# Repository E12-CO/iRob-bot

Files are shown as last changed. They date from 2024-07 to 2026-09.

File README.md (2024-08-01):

# iRob-bot

iRob-bot is a robot testing platform for Arduino and ROS2.
The goal is to have a autonomous robot with good odometry accuracy while having a simple motion control system that capable of manuvering complex movement.  

This robot is a part of R&D project at Robot club engineering KMITL (RB26).

# Why iRob-bot ?

Our club has a long experience with Mechanical and Electronics design. We have been doing these kind of works for almost three decades. But when it comes to autonomous robot. We're very new to this and still lacking a lot of fundamental skill such as motion control and planning. At the competition, our manual control robot worked very hard to gain a good amount of score, while our autonomous robot struggled to do a mission, let alone walking straight. 

Back in december 2023, there was a competition called ```CRU Robot Games```. 
This competition which each team has to compete using one manual control robot 
and one autonomous robot. In fact, we also participated in this same competition 
but without much success as we are very new to autonomous robot. (I personally participated back in 2022, That also my first time working with closed-loop 
control of DC motor with the autonomous robot, but again without much success).

There was a 3 wheeled omni robot from a team ```iRap```(robotics club from KMUTNB). I was intrigued by their autonomous robot, especially the motion control. Somehow it can do advanced motion like translational motion while also rotates 
around its own axis, or following the curve arc while also rotates around.

At the time I saw their robot in-action. I've had some previous experience from joining the club and working with holonomic robot (using mecanum/swiss wheel) . 
But nothing of us every came close to theirs. And we are still using ```robot oriented``` control. At best our robot did equiped with encoder and PI speed controlled for motor. But the robot still lack of a good motion
control system.

Tragidy strikes. Our club got critizied with a surprise budget cut by half. The reason was that we ```don't have a real work``` a.k.a we never win any of these competition despite a lots of work behind and knowledge that we gained and poured into each competition.

In out defense, we decided to start a R&D project to research and test out around the topic of robotics. The goal is to gain knowledge as much as possible to be used in competition. But also to prove them that every cent that we spend is turned into know-how that we then pass down to the next club member generation. 

This year is my last year at university as I will (hopefully) be graduated soon. I want to do something to help our junior members as a payback to what this club had taught me from the past 2 years. So I set out to learn and implement the motion control system. 

This is a good oppurtunity for me to revisit what I've seen back in 2023. I finally came up with a robot test platform called ```iRob-bot```, basically I "rob" the idea of using 3 wheeled omni robot from iRap, hence the name iRob-bot. along with the motion controller called ```Maneuv3r``` that will be on arduino and ROS2. 

# General Information

- Dimension : ⌀ : 145.4mm, Height included LiDAR : ~ 130mm
- Weight : ~0.4 kg
- Drivetrain ```omnidirectional 3 wheels (omni-wheel)```
- Motor ```N20 motor with 1:48 gearbox and 7PPR AB quadrature encoder```
- Drive ```DRV8835 on custom breakout board(sees Electronics folder)```
- Main controller ```ESP32 WROOM32```
- Odometry sensors
    - ```Wheel encoder``` (Moving average filtering)    
    - ```ADNS-5050``` optical flow sensor 
	- Wheel odometry and Optical Flow odometry fusion using ```complementary filter```
- IMU via I2C (9 axis GY-85 module)
    - ```ADXL345``` 3 axis Accelerometer (currently unused until I can implement EKF)
    - ```ITG3205``` 3 axis Gyro sensor
    - ```HMC5883L``` 3 axis Mag sensor (currently unused until I can implement EKF)
- LiDAR
    - ```HLS-LF2CD``` LiDAR (currently unused until I implemented ROS2 node)
- Digital Control running at ```125Hz```
    - PI speed control (No torque control)
    - PID position and orientation control
- ESP32 Dual core
    - Core 0 is working on Low-level control system
    - Core 1 is responsible for Networking task (BR/EDR or WiFi) and LiDAR reading (Work in progress)

# Folders
- Documents : Schematic and diagram PDFs and more soon.
- Electronics : Electronics design file (EAGLE cad and Fusion 360 format)
- Firmware : Arduino firmware
- Hardware : CAD design of the robot in Fusion 360 archive
- Software : ROS2 node (Coming soon)

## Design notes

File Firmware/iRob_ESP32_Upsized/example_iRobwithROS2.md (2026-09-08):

# Driving iRob with `teleop_twist_keyboard`

This guide is for anyone using the iRob ROS 2 workspace with the four-wheel
omni ESP32 robot. It assumes you are already in a terminal where ROS 2 is
available and the `ROS_iROB_V0` workspace overlay has been sourced.

The control path is:

```text
teleop_twist_keyboard -- /cmd_vel --> iRob_controller
    -- /irob_motor_cmd --> iRob_interface -- /dev/ESP32 --> ESP32
```

The current controller configuration uses the `Omni4` kinematic plugin. You
do not need to publish motor commands yourself; the controller converts the
keyboard velocity commands into four motor commands.

## Before driving

1. Turn off or lift the robot so the wheels cannot move unexpectedly.
2. Upload the ESP32 sketch in this directory. The firmware serial rate is
   `115200` baud.
3. Connect the ESP32 by USB. Ensure `/dev/ESP32` exists and points to the
   connected ESP32:

   ```bash
   ls -l /dev/ESP32
   ```

   If it does not exist, install the udev rule once:

   ```bash
   sudo cp src/iRob_bot_ros2/irob_controller/esp32.rules /etc/udev/rules.d/
   sudo udevadm control --reload-rules
   ```

   Unplug and reconnect the ESP32 after installing the rule.
4. Build the workspace after any source-code or parameter-file change, then
   source its overlay:

   ```bash
   colcon build --packages-select irob_interface irob_controller irob_launcher --symlink-install
   source install/setup.bash
   ```

## Start the robot nodes

Open three terminals after completing the setup above. ROS commands in each
terminal must use the same ROS domain and workspace overlay.

### Terminal 1: ESP32 interface

This node sends motor commands to the ESP32 and publishes motor feedback.

```bash
ros2 launch irob_launcher irob_interface_esp32.launch.py
```

### Terminal 2: kinematic controller

This node receives `/cmd_vel` and calculates the four wheel speeds.

```bash
ros2 launch irob_launcher irob_controller.launch.py
```

### Terminal 3: keyboard teleoperation

Install the keyboard package if needed:

```bash
sudo apt install ros-$ROS_DISTRO-teleop-twist-keyboard
```

Start at a low speed:

```bash
ros2 run teleop_twist_keyboard teleop_twist_keyboard --ros-args -p speed:=0.15 -p turn:=0.5
```

Keep this terminal focused while driving. `teleop_twist_keyboard` publishes
`geometry_msgs/msg/Twist` on `/cmd_vel`; no remapping is required.

## Keyboard controls

```text
u  i  o
j  k  l
m  ,  .
```

- `i`: forward
- `,`: backward
- `j` / `l`: strafe left / right
- `u`, `o`, `m`, `.`: diagonal motion
- `q` / `e`: rotate counter-clockwise / clockwise
- `k` or `Space`: stop immediately

For this Omni4 firmware, motor order is left-front, left-back, right-back,
right-front. If a direction is wrong, stop the robot and correct motor wiring
or the wheel-direction configuration before further driving.

## Verify the command path

Run these in a fourth sourced terminal while pressing a teleop key:

```bash
ros2 topic info /cmd_vel
ros2 topic echo /irob_motor_cmd
```

`/cmd_vel` should have `teleop_twist_keyboard` as a publisher and
`iRob_controller` as a subscriber. `/irob_motor_cmd` should change while a
movement key is pressed.

## Common problems

| Problem | Check |
| --- | --- |
| `/dev/ESP32` does not exist | Reconnect the board and install the udev rule in the “Before driving” section. |
| Interface cannot open the serial port | Ensure no packet-test program or serial monitor is using `/dev/ESP32`; confirm your user belongs to the `dialout` group. |
| Keyboard keys do not move the robot | Keep the teleop terminal focused, then run `ros2 topic info /cmd_vel` and confirm the controller is running. |
| Robot moves in the wrong direction | Press `Space` immediately. Verify the Omni4 motor order and wheel directions before trying again. |
| Robot does not stop after closing teleop | Use the physical emergency stop or remove motor power; do not rely on a closed terminal as a safety stop. |

## Safety

Lift the wheels off the ground for the first test. Keep a hand near the power
disconnect or emergency stop. Always press `Space` or `k` before switching
terminals or stopping a ROS node.

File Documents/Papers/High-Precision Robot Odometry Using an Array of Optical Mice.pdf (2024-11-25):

# High-Precision Robot Odometry Using an Array of Optical Mice

Steven Bell Student Member, IEEE

IEEE Student Member No. 90691022

Oklahoma Christian University

18 March 2011

ORIGINALITY STATEMENT
I was the sole author of this paper, and all of the images, diagrams and graphs were captured in the lab or created by me except where noted. The algorithms for calculating the robot position using an array of sensors are based on research by others, but the use of surface quality measurements as a means of checking displacement readings is original. I built and programmed the test system described within this paper to validate the concepts and algorithms.

ACKNOWLEDGEMENTS
I am grateful for Dr. David Waldo’s guidance during this project and for his support of the Oklahoma Christian IEEE student branch, and to Dr. Bill Ryan for his help in the manufacturing aspects of this work. I would also like to thank Avago Technologies, Marshall Electronics, and M12 Lenses, Inc, for supplying free and discounted parts for this project.

CONTENTS

I | Introduction | 3
I-A | Prior research | | 3
I-B | Conditions for mouse use | | 4
II | Sensor design | 4
II-A | Hardware design | | 5
II-B | Software driver | | 5
III | Motion tracking | 5
IV | Error reduction | 7
IV-A | Integration of multiple sensors | | 7
IV-B | Use of encoder data | | 7
IV-C | Use of surface quality | | 8
V | Additional uses | 8
VI | Conclusions and Future work | 8
References | 9
Appendix | 10
A | Optical mouse theory of operation | | 10
B | Lens comparison and selection | | 10

Abstract

This paper describes a robot position tracking system based on a set of six optical mice. Each mouse sensor uses a lens which results in higher tracking speeds and allows the sensor to be placed centimeters, rather than millimeters, from the floor. The sensors’ tracking and data reporting characteristics are discussed, and an algorithm is presented to determine a robot’s motion from the sensor readings. Techniques for error detection and correction are presented, along with methods to use the sensor for line following and edge detection.

I. INTRODUCTION
F

OR decades, dead-reckoning has been a staple of mobile robot navigation. For ground-based robots, this has typically been accomplished by using a set of shaft encoders mounted to the robot’s wheels to measure speed and distance. While this method is simple and well-tested, it suffers from one primary drawback: any time the wheel slips on the surface it will cause an error in the position measurement. This is a major handicap for omnidirectional drivetrains based on omniwheels or mecanum wheels, which by their nature slide easily and can slip in any direction [1]. The encoder approach also suffers in competition environments where the robot is likely to physically collide with obstacles or even be pushed by other robots, causing wheel slip.
Traditionally, computer mice have been plagued with many of the same problems. Achieving accurate motion with a mechanical ball is difficult due to surface differences, dust, and wear. Optical mice based on high-speed optical flow solve these problems, and they have completely supplanted traditional ball mice over the last ten years. The underlying operation of optical mouse sensors has been discussed extensively in prior research [2]–[4], and is summarized in Appendix A.
This paper presents a means of using optical mice as position sensors by pointing them at the floor and reading motion data from them. A robot navigation system based on optical mice has several notable advantages over wheel-based encoders. First, it has no moving parts and does not need to be in contact with the floor, which ultimately reduces friction and wear on the system. Second, all of the mouse chips on the market track motion in two dimensions simultaneously, and do so at increasingly high resolutions - up to five thousand counts per inch (CPI) [5]. Mouse chips typically come in 8 or 16-pin integrated circuit packages, which means they are both small and easy to mount. Finally, the sensors are abundant and inexpensive: Avago Technologies has shipped over 0.8 billion mouse sensors [6], and typical chips cost less than a dollar apiece in bulk.
A. Prior research

Researchers, undergraduates, and hobbyists have been experimenting with optical mice as sensors for robot navigation for the last decade. Most of the published papers and reports take one of three approaches: One set of projects has focused on the validation of the optical mouse sensor as a means of robot position tracking and the development of algorithms to achieve robust 3-degree-of-freedom (3-DOF) tracking with an array of sensors [7]–[12]. That is, they combine the data from multiple sensors to measure a robot’s translation in two dimensions plus rotation. Nearly all of these projects use the mouse chips in their intended configuration - they are placed within millimeters of the tracking surface and utilize the commercial-off-the-shelf (COTS) lens and illumination LED. Many of these systems use complete circuit boards and even plastic shells taken from commercial optical mice.
A second area of research has been to carefully characterize particular sensors. Several findings are particularly relevant: although the sensor measures motion very precisely and repeatably [4], it has limitations.
While the sensor is within its working height range, the resolution (in CPI) is a linear function of height. When the sensor is raised further from the surface, it sees a larger patch of the tracking surface, and each pixel represents a larger distance. Because the sensor tracks movement using pixel displacement, one inch of motion will give a higher distance count when the sensor is close than when it is far away [3]. When the sensor is outside of its working focal range, the measured distance drops off sharply.
The measured displacement appears to vary depending on the orientation of the sensor relative to the direction of motion [3], [4]. There are two reasons for this. Many common surfaces - including paper, which is a popular test surface - exhibit a grain. That is, they have a directional surface pattern that may result in better tracking in some dimensions versus others. Moreover, [4] and [13] show that one axis consistently reports higher measurements than the other - a surprising find, given that the chip’s internal algorithm is presumably indifferent to the movement direction. This is caused by the fact that the standard design for optical mice includes a single light source along one axis, causing it to track more accurately than the other [13]. Using two orthogonal light sources eliminates this effect.
Finally, the sensor readings are strongly dependent on the surface, which means that the sensor must be calibrated for each new environment, and it will not work reliably in situations where the surface is not uniform [3].
The third research area is the application of optical mice to a variety motion tracking problems where the robot is not within millimeters of the tracking surface. This requires the use of a non-standard lens to refocus the light onto the sensor at a different distance. This approach has been shown to work across a wide range of distances, from mobile robots less than 2 cm above the surface [14] to robots flying tens of meters above the ground [15]. This paper synthesizes these threads of research to create a system based on a set of optical mice which can be used for robust and precise robot navigation.
B. Conditions for mouse use

Based on the research discussed above, there are several constraints which inform the use of optical mice as planar 3-DOF position sensors. First, the tracking surface should have a uniform and unstructured texture - that is, it should not have a grain or other directional pattern which will favor tracking in one direction over another. Second, the environment must allow calibration of the sensors prior to their use. Finally, the surface should be flat, so that the distance from the sensor to the surface is essentially constant.
These constraints make the optical mouse unsuitable for many applications, but in other domains - such as small scale robotics contests - these constraints are not a problem. With these limitations in mind, we proceed with the design of our system.

II. SENSOR DESIGN

The proposed system is a small, 2-wheel differential drive robot for the IEEE Region 5 robotics competition which uses a set of six optical mouse sensors for navigation. Four sensors are located across the front and two are placed in the back corners. A rendering of the robot base is shown in Figure 1. Encoders are also mounted on the wheels for speed control; their integration is described in Section IV-B. The competition playing field is made of fiberboard painted flat white, which provides a uniform tracking surface for the mouse sensors.

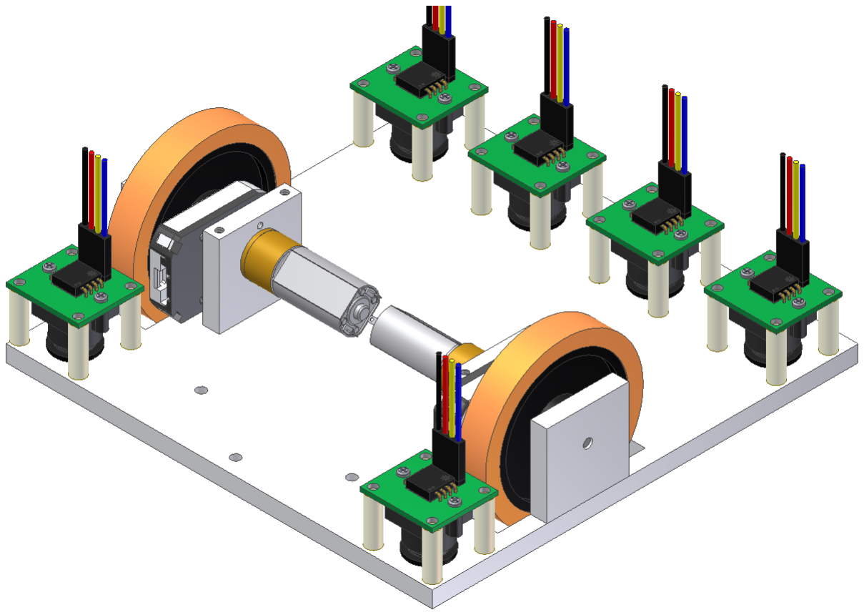
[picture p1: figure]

Figure 1: Simplified rendering of the robot base showing the location of the six sensors.

[16] and [2] show mathematically that for optimal performance, the array of sensors should be evenly spaced, located as far from the center of the robot as possible. Because of the additional sensor uses described in Section V, our placement deviates from the optimum. However, the sensors are all located near the edge of the robot, which will still provide very good tracking.

A. Hardware design
The sensor system is based on the Avago Technologies ADNS-2610 and the pin-compatible ADNS-5060. Both sensors have the same form factor and communication interface; the primary difference is in the rated tracking speed. The mouse chip is mounted on a custom printed circuit board which contains a header for connection to a microcontroller and decoupling capacitors as suggested by the sensor datasheet. A COTS lens holder is screwed onto the bottom of the PCB and a standard M12 lens is threaded into it. By using a standard lens mount, it is simple to connect a variety of lenses to the system for testing. A lens with a 3.6 mm focal length was selected for the ADNS-2610; a detailed comparison of lens focal lengths and selection criteria is given in Appendix B. An exploded view of the sensor assembly is shown in Figure 2a and a photograph of the assembled unit in Figure 2b.

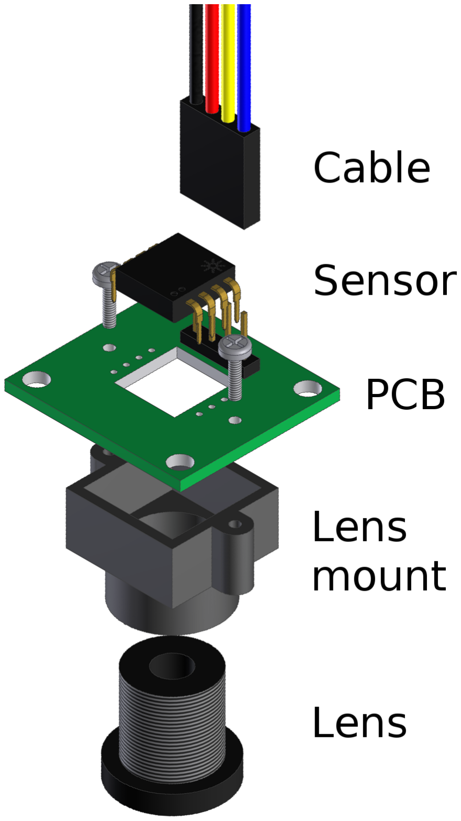
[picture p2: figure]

(a) Exploded view of the sensor assembly

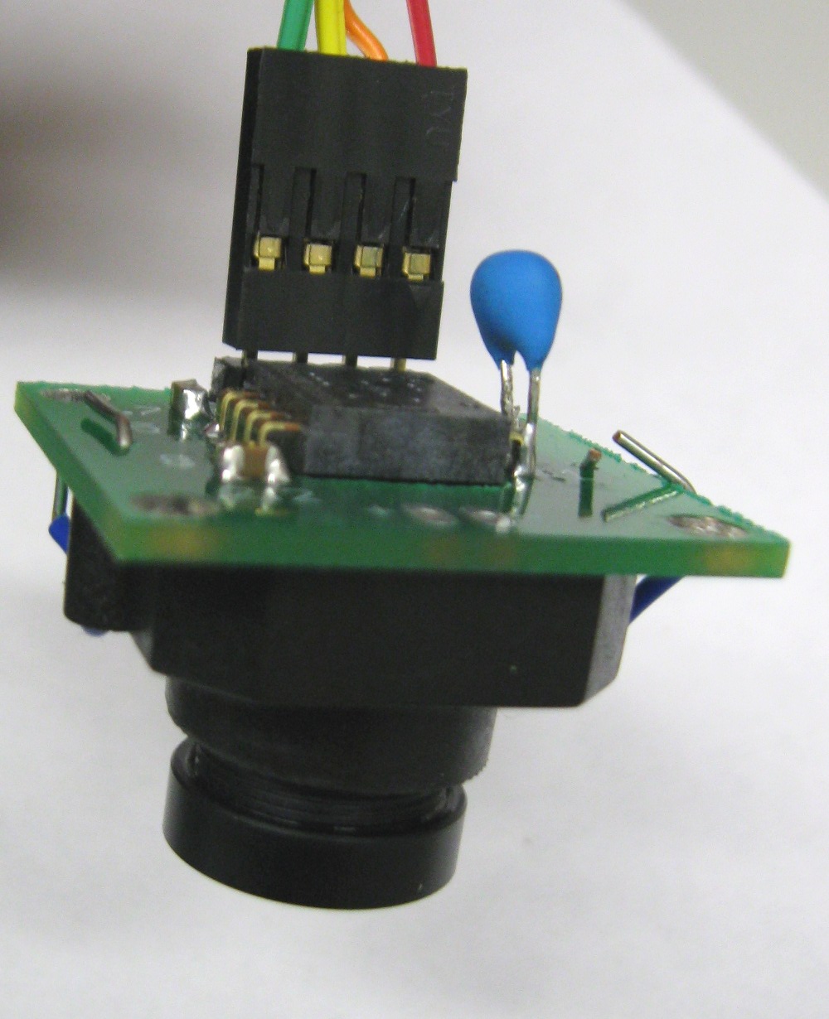
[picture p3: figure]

(b) Photograph of the sensor assembly

Figure 2: Rendering and photograph of the sensor assembly. 3-D models of mouse chip and lens mount courtesy of Avago Technologies and Marshall Electronics respectively.

B. Software driver
Most of Avago’s mouse chips share a common synchronous serial interface to a set of internal registers which contain the tracking data. In a typical mouse, a microcontroller interfaces with the mouse chip, integrates the buttons and mouse wheel, and provides a USB connection to the host PC. In our application, the control hardware (an Arduino microcontroller board) is wired directly to to the mouse sensor so that we have direct access to all of the chip’s registers, not merely the motion reports. The chip provides several pieces of data:
- X and Y differential motion values, which report the number of “counts” since the last time the register was read.
- A Surface Quality (SQUAL) measurement, which gauges how suitable the surface is for tracking. A higher SQUAL value indicates a higher number of tracking features, and generally corresponds to a more accurate distance measurement. Lower SQUAL values indicate that the surface is especially smooth and featureless or that the camera is not properly focused on the tracking surface.
- The imager shutter speed, which can be used to derive the brightness of the tracking surface. High (longer) shutter values indicate a darker surface, low values indicate a bright surface.
- The sensor also provides a means of capturing image data directly from the sensor, which was used to obtain the mouse images presented in the Appendix.
The software provides methods for reading each of these values, and communicates with a GUI running on a PC which can display the data in real time.

III. MOTION TRACKING
There are three important frames of reference in the motion tracking problem, which are shown in Figure 3. The first is the absolute coordinate frame, designated by the Cartesian coordinates XA and YA. The second is the robot frame of reference, specified by XR and YR. The final reference frame is aligned with each sensor’s measurement axes and is designated xi and yi
. Note that although only one mouse sensor is shown in Figure 3, there can be an arbitrary number of mice, and their reference frames will be labeled x1, x2, x3 and so forth. We can also reference these points using a polar coordinate system, which will be useful in later derivations. The robot’s position in absolute coordinates is given by rR and θR, while each mouse’s position is given by ri and θi
. Each mouse’s
rotation relative to the robot is labeled φi

Figure 3: Important frames of reference: absolute coordinates, robot coordinates, and mouse coordinates.

Using these definitions, we can relate the 3-dimensional motion of the robot to the motion of each mouse.

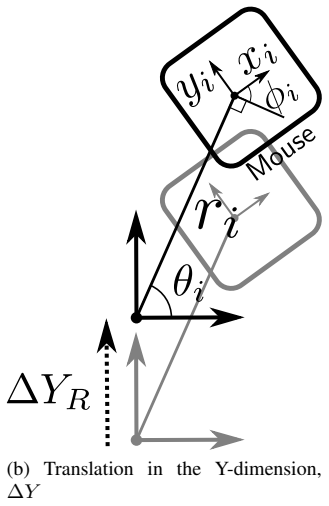
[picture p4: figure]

(a) Translation in the X-dimension, ∆X | (b) Translation in the Y-dimension,
(c) Rotation about the robot center, ∆ω

Figure 4: Three possible movements for the robot base and the resulting motion measured by the optical mouse sensor.

If the robot base translates by ∆XR as shown in Figure 4a, then the mouse will also translate by ∆XR. Because the mouse has a different orientation than the robot, the values measured by the mouse axes xi and yi will be:

xi = ∆XR · sin (θi + φi) | (1)
yi = ∆XR · cos (θi + φi) | (2)

Likewise, if the robot translates by ∆YR, the sensors will measure

xi = −∆YR · cos (θi + φi) | (3)

yi = ∆YR · sin (θi + φi) | (4)

If the robot rotates around its center by ∆ω (where ω is in radians), the mouse will travel a distance of ∆ω · ri
The measurements along the mouse axes will be

xi = −∆ω · ri

- cos (φi) | (5)

yi = ∆ω · ri

- sin (φi) | (6)

We can add equations 1, 3, and 5 to get the total motion measured by the sensor x-axis:

xi = ∆XR · sin (θi + φi) − ∆YR · cos (θi + φi) − ∆ω · ri

- cos (φi) | (7)

And we can do the same for the y-axis with equations 2, 4, and 6:

yi = ∆XR · cos (θi + φi) + ∆YR · sin (θi + φi) + ∆ω · ri

- sin (φi) | (8)

Since we know the motion of each sensor, we can put those values into equations 7 and 8 and solve for ∆X, ∆Y , and ∆ω. With only one sensor, we have 2 equations and three unknowns, but each additional sensor provides two more solutions to these equations. With six sensors, we have a total of 12 equations and three unknowns. This is an overconstrained system, and because of errors there will be no solution which can satisfy all 12 equations. Instead we use a linear least squares algorithm to find the “best fit” for the data. Mathematically, this is equivalent to finding the linear trendline for a set of data points.
The answer to the linear least squares optimization can be found by creating a matrix with the coefficients (which for a given mouse configuration are constants) and taking the Moore–Penrose pseudoinverse. Multiplying the pseudoinverse matrix by the measurement matrix produces a matrix with the estimated robot movements ∆X, ∆Y , and ∆ω [2]. Once the robot’s relative motion is determined, translating this value back to absolute coordinates is trivial.

IV. ERROR REDUCTION
Although the individual sensors are very accurate and averaging them together provides even greater accuracy, they are still subject to errors. Ideally, the system should detect which sensor readings are incorrect and discard them in favor of measurements known to be more correct. There are several techniques which we can use to detect these errors, which are described in the following sections.
After detecting the errors, we must account for them in the position estimation algorithm described in the previous section. To do this, we extend the linear-least-squares algorithm to be a weighted linear-least-squares algorithm. That is, rather than trying to make the solution fit all of the points equally, it favors some over others. Each measurement is given a weight: A high weighting factor causes the derived equation to fit a data point very closely (at the expense of a looser fit at other points), while a factor of zero forces a data point to be completely ignored.
A. Integration of multiple sensors
In [7], several assumptions are made about the characteristics of the mouse sensors which are used to detect and correct for errors. In general, mouse sensors do not measure a distance greater than the actual distance traveled. The optical flow algorithm may miss counts due to poor focus or insufficient frame overlap, but it will not overestimate the motion. Thus, when there is disagreement between one or more sensors, the sensor with the higher measurement is probably correct.
B. Use of encoder data
The proposed robot system also has a pair of rotary encoders placed on the wheels, which provide very precise angular measurement (8192 counts per revolution). In the same way that multiple mouse sensors can be compared against each other to determine which is more accurate, the mouse sensors can be compared against the encoder readings to detect errors.
Except for rare circumstances when quickly decelerating, the robot will not move further than indicated by the encoders. In almost all situations, wheel slip will cause the encoders to measure a distance equal to or higher than the actual. By contrast, the mouse sensors will measure a value less than or equal to the actual. Thus if the mouse sensors and encoders agree exactly, then the motion estimate is very good. If they disagree, there is an error -although the system cannot directly determine whether the encoder or mouse (or both) is incorrect.

C. Use of surface quality

Each mouse sensor also provides an estimate of its accuracy - the SQUAL reading. In general, lower surface qualities will result in lower measured distances for a given speed. At one extreme, an SQUAL reading of zero indicates that the sensor has no features to track, and thus it will fail to report any motion. The robot can average surface quality measurements from all of the sensors, and then lower the weights of the sensors with below-average surface qualities. Any sensor with a surface quality in the single digits should be completely ignored.

V. ADDITIONAL USES

Besides its obvious use as a motion tracking sensor, the Avago mouse chips have other unexploited applications on mobile robots. In [17], it is shown by reading the shutter value, the mouse sensor can be used to detect light and dark areas on the surface. The shutter readings can be interleaved with motion readings, allowing our motion tracking sensors to simultaneously double as line following sensors. Figure 5 shows a plot of the surface brightness as the sensor was moved over a dark line. When the sensor is over the line, the shutter time reaches its maximum, and the surface quality drops to about 15. By monitoring these readings, the robot can easily differentiate white and black surfaces.

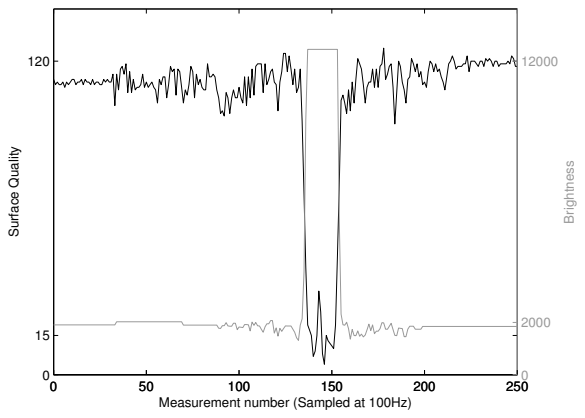
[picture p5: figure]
Measurement number (Sampled at 100Hz); Surface Quality; Brightness

Figure 5: Plot of the shutter value as the mouse was moved across a black line. Higher brightness values indicate darker surfaces, i.e, longer shutter times.

The narrow focus range of the sensor can also be used advantageously. As described earlier, the surface quality is highest when the target surface is in sharp focus and drops to zero when no surface is beneath the sensor. By reading the SQUAL continuously, the robot can detect if one of the sensors has run off the edge of the playing field and take corrective action. Figure 6 shows a plot of the surface quality as the lens-based sensor moves off the edge of the surface. Although the sensor readings are similar to those shown above for crossing a line, here the surface quality drops to less than 5, which indicates that the tracking surface has disappeared altogether.

VI. CONCLUSIONS AND FUTURE WORK

Optical mice provide a promising option for robot motion tracking, provided the environment is accommodating. The design we have presented in this paper allows small and inexpensive lenses to be used to give higher tracking speeds and reduce height sensitivity, and the algorithms presented can be used to detect and eliminate errors, taking full advantage of sensor redundancy.
To build upon this work, we have built a test jig to carefully characterize the lens-based sensor units. For a given set of focal lengths, we plan to determine the working height range of the sensor and maximum working speed of the sensor. Finally we will determine whether there is a reliable mathematical relationship between surface quality and recorded distance, which will be used to refine the error-correction algorithm.

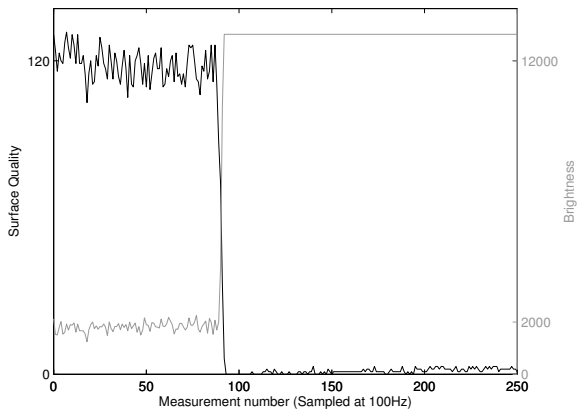
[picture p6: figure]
Measurement number (Sampled at 100Hz); Surface Quality; Brightness

Figure 6: Plot of the surface quality (SQUAL) reading as the mouse was moved over the competition surface and off the edge.

REFERENCES

[1] J. A. Cooney, W. L. Xu, and G. Bright, “Visual dead-reckoning for motion control of a mecanum-wheeled mobile robot,” Mechatronics, vol. 14, no. 6, pp. 623–637, 2004.
[2] D. Sorensen, “On-line optical flow feedback for mobile robot localization/navigation,” Master’s thesis, Texas A&M, May 2003.
[3] J. Palacin, I. Valgañon, and R. Pernia, “The optical mouse for indoor mobile robot odometry measurement,” Sensors and Actuators A: Physical, vol. 126, no. 1, pp. 141–147, 2006.
[4] U. Minoni and A. Signorini, “Low-cost optical motion sensors: An experimental characterization,” Sensors and Actuators A: Physical, vol. 128, no. 2, pp. 402–408, 2006.
[5] Avago ADNS-9500 Datasheet, Avago Technologies. [Online]. Available: http://www.avagotech.com/docs/AV02-1726EN
[6] Company history. Avago Technologies. [Online]. Available: http://www.avagotech.com/pages/corporate/company_history/
[7] A. Bonarini, M. Matteucci, and M. Restelli, “Automatic error detection and reduction for an odometric sensor based on two optical mice,” in Robotics and Automation, 2005. ICRA 2005. Proceedings of the 2005 IEEE International Conference on, Apr. 2005, pp. 1675–1680.
[8] J.-S. Hu, Y.-J. Chang, and Y.-L. Hsu, “Calibration and on-line data selection of multiple optical flow sensors for mobile robot localization,” in Intelligent Robots and Systems, 2008. IROS 2008. IEEE/RSJ International Conference on, Sep. 2008, pp. 987 –992.
[9] S. Lee, “Mobile robot localization using optical mice,” in Robotics, Automation and Mechatronics, 2004 IEEE Conference on, vol. 2, Dec. 2004, pp. 1192–1197.
[10] S. Kim and S. Lee, “Robust mobile robot velocity estimation using redundant number of optical mice,” in Information and Automation, 2008. ICIA 2008. International Conference on, Jun. 2008, pp. 107–112.
[11] D. Sekimori and F. Miyazaki, “Precise dead-reckoning for mobile robots using multiple optical mouse sensors,” in Informatics in Control, Automation and Robotics II, J. Filipe, J.-L. Ferrier, J. A. Cetto, and M. Carvalho, Eds. Springer Netherlands, 2007, pp. 145–151.
[12] S. Singh and K. Waldron, “Design and evaluation of an integrated planar localization method for desktop robotics,” in Robotics and Automation, 2004. Proceedings. ICRA ’04. 2004 IEEE International Conference on, vol. 2, May 2004, pp. 1109–1114.
[13] N. Tunwattana, A. Roskilly, and R. Norman, “Investigations into the effects of illumination and acceleration on optical mouse sensors as contact-free 2d measurement devices,” Sensors and Actuators A: Physical, vol. 149, no. 1, pp. 87–92, 2009.
[14] J. Bradshaw, C. Lollini, and B. Bishop, “On the development of an enhanced optical mouse sensor for odometry and mobile robotics education,” in System Theory, 2007. SSST ’07. Thirty-Ninth Southeastern Symposium on, Mar. 2007, pp. 6–10.
[15] S. Thakoor, J. Morookian, J. Chahl, D. Soccol, B. Hine, and S. Zornetzer, “Insect-inspired optical-flow navigation sensors,” NASA Jet Propulsion Laboratory, Tech. Rep. NPO-40173, Oct. 2005.
[16] M. Cimino and P. Pagilla, “Location of optical mouse sensors on mobile robots for odometry,” in Robotics and Automation (ICRA), 2010 IEEE International Conference on, May 2010, pp. 5429–5434.
[17] M. Tresanchez, T. Pallejà, M. Teixidó, and J. Palacín, “The optical mouse sensor as an incremental rotary encoder,” Sensors and Actuators A: Physical, vol. 155, no. 1, pp. 73–81, 2009.
[18] Avago ADNS-2610 Datasheet, Avago Technologies. [Online]. Available: http://www.avagotech.com/docs/AV02-1184EN

APPENDIX

A. Optical mouse theory of operation

An optical mouse chip consists of a tiny camera, a digital signal processing (DSP) engine, a serial interface, and appropriate electronics to regulate power and drive the illumination LED. The camera runs at a frame rate of over one thousand frames per second, capturing a grayscale image of a tiny patch of the tracking surface. The DSP engine continuously compares each frame to the one before it, using optical flow algorithms to estimate the relative motion of the sensor. Figure 7 shows two images of the letter ‘e’ in size 6 font with a small amount of movement between the two frames. The DSP hardware within the chip compares these two images and determines that the mouse has moved about two pixels to the right.

Figure 7: Two images captured from a modified mouse with a tiny amount of movement between them.

A cross section of a typical mouse is shown in Figure 8. The sensor, clip, LED, and lens/light pipe are all provided by Avago Technologies; the mouse manufacturer supplies the baseplate, plastic shell, buttons, scroll wheel, and typically the PC interface hardware.

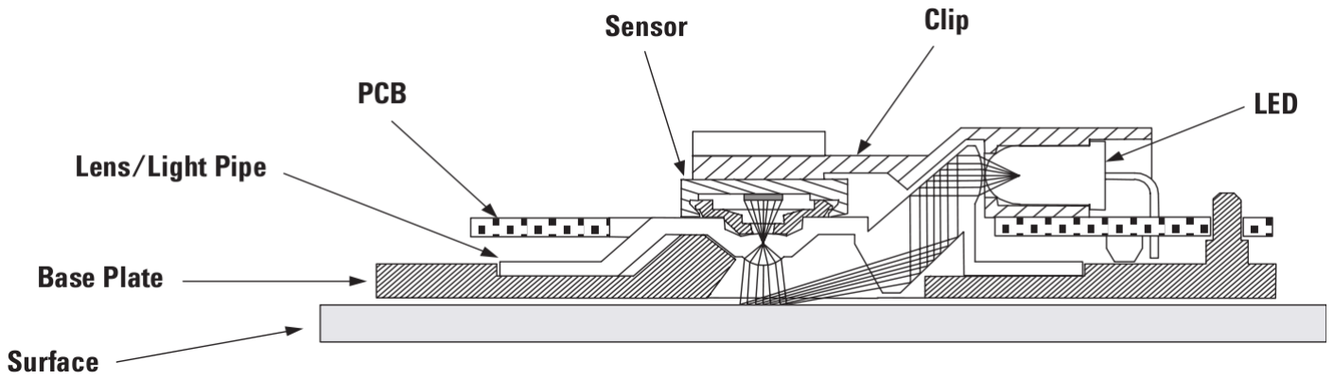
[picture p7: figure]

Figure 8: Cross section of a typical optical mouse. Image taken from the Avago ADNS-2610 datasheet [18].

Laser mice work on identical principles, but use a small infrared laser for illumination rather than a visible-light LED. The laser produces a much sharper image and brings out surface features more clearly, which is why laser mice typically have better tracking performance on smooth surfaces than traditional optical mice. Optical mice were used in this work because they are more commonly available and it is easier to provide visible-light illumination. A comparison of several Avago sensors is shown in Table I.

Table I: Comparison of several Avago sensors

Name | Type | Rated resolution (counts/inch) | Rated speed (inches/sec) | Imager resolution
ADNS-2610 | Optical | 400 | 12 | 18×18 pixels
ADNS-5060 | Optical | 1050 | 30 | 19×19 pixels
ADNS-7050 | Laser | 800 | 20 | 22×22 pixels
ADNS-9500 | Laser | 5000 | 150 | 30×30 pixels
B. Lens comparison and selection

An important part of the sensor package design is the selection and placement of the lens. The primary criterion is that the lens provide a magnification that increases the maximum tracking speed of the sensor. A second criterion is the object-to-image distance, the distance between the tracking surface and the imaging sensor inside the mouse chip. For our application, we desire a tracking speed of at least 45 inches per second. The vertical placement of the sensor is negotiable, but should be between 2 and 4 cm above the surface. A diagram of the setup is shown in Figure 9.

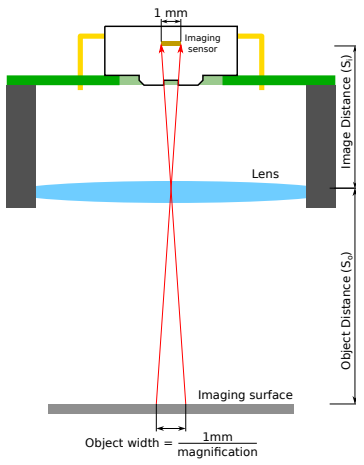
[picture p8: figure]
Imaging surface; Lens; Imaging sensor; 1mm magnification; Object Distance (S; o) Image Distance (S )i; Object width =

Figure 9: Cutaway view of the idealized lens system. Note that although the lens used in the system is a compound lens rather than a thin lens, for the purposes of this analysis it can be treated the same way based on its effective focal length (EFL).

From the Avago sensor and lens datasheets, we can determine that the standard lens provides a magnification very close to 1. That is, the area of the surface that is recorded is the same size as the camera itself. Based on this information, the desired magnification is determined by dividing the rated tracking speed by the desired speed:

30 inches
second
45 inches
second

=

2
3
≈ 0.67 | (9)

This means that a 1.5 mm wide patch of the surface will be focused onto the 1 mm wide image plane within the sensor.
For a particular focal length f , we can relate the object distance So, and the image distance Si using the lens equation:
1
f

=

1
So

+

1 Si | (10)

We also know that the magnification, m, is given by

m =

Si
So
| (11)

Combining equations 10 and 11 we get 1
f

=

1
So

+

1 m · So | (12)

and solving for So gives us

So = f +

f m | (13)

We can find Si using Equation 11 and add So and Si
to find the total object-to-image distance. This set of equations is plotted in Figure 10 for a series of commonly available focal lengths.
Figure 11 compares the images captured from the sensor using a constant height above the surface and varying focal lengths. Lower focal lengths provide a wider view; high focal lengths provide a “zoomed in” view.
Based on Figure 10, a focal length of 6 mm is most appropriate for the ADNS-5060. The ADNS-2610 used in
the experiments has a tracking speed of only 12 inches per second (304.80 mm | second ), so a larger magnification is
necessary. A focal length of 3.6 mm was selected for testing.

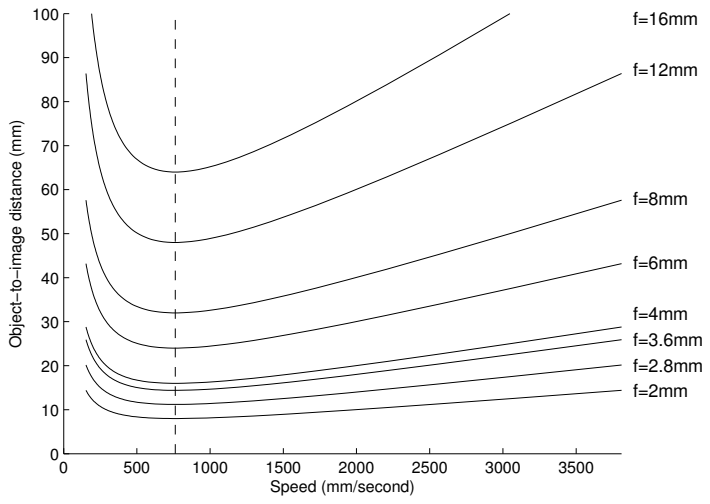
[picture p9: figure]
Speed (mm/second); Object−to−image distance (mm)

Figure 10: Plot of the object-to-image distance as a function of focal length and tracking speed. Each line represents a particular fixed focal length. The vertical dashed line shows a magnification of 1, which gives the rated tracking speed of 30 inches per second (762 mm
second ).

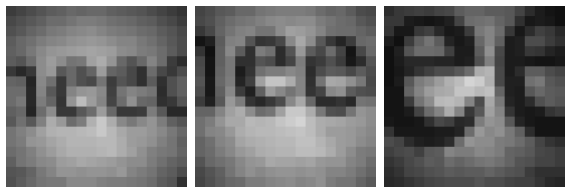
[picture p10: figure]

(a) 3.6 mm | (b) 4.0 mm | (c) 6.0 mm
Figure 11: Comparison of focal lengths. The sensor PCB was placed 1.0 inches above a piece of paper with 6-point type, and each lens was focused appropriately.

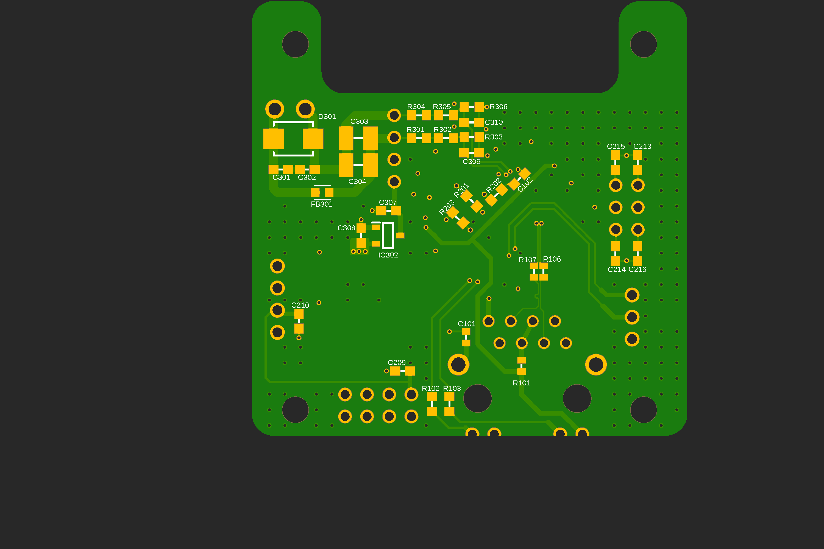
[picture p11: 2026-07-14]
Documents/Elec/iRob_ETH_PCB_bottom.png

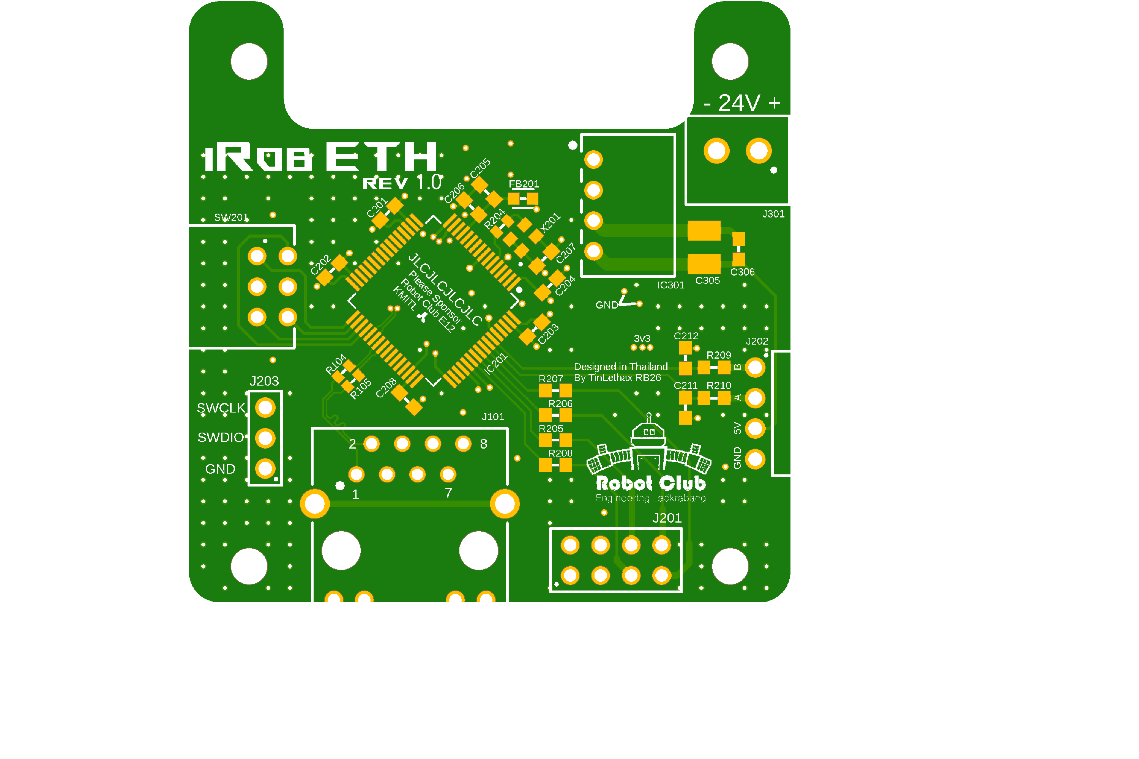
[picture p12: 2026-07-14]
Documents/Elec/iRob_ETH_PCB_top.png

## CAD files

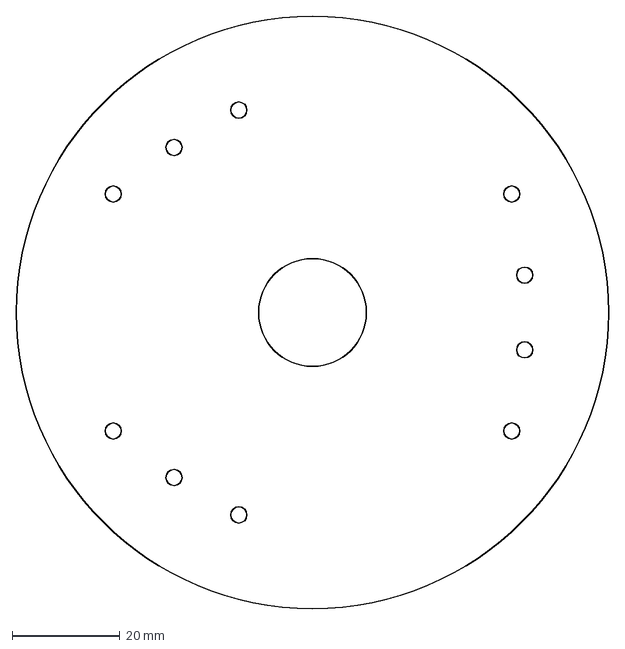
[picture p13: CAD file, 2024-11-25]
Hardware/iRob_BasePlate_1.dxf
110.0 x 110.0 mm

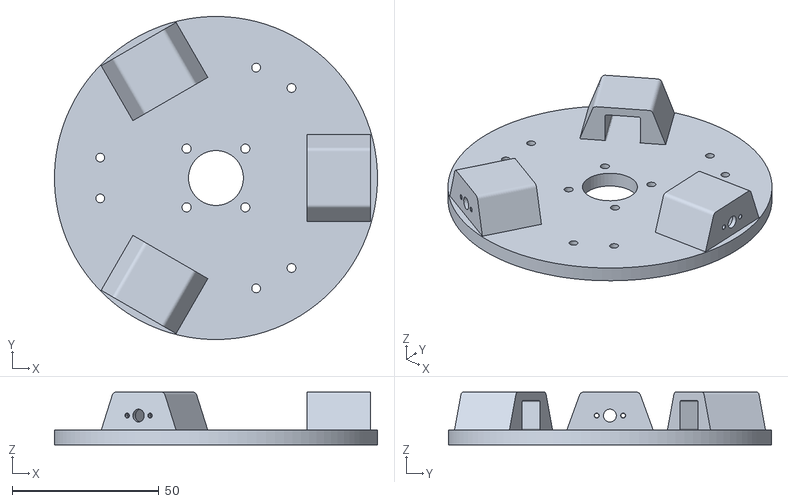
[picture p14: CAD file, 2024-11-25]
Hardware/iRob_chassis_v1.stl
110.0 x 110.0 x 18.0

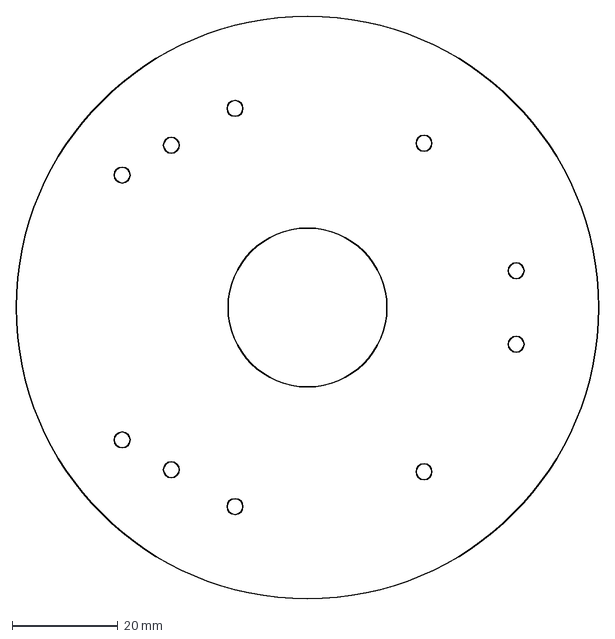
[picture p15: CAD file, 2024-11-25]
Hardware/iRob_BasePlate_LiDAR.dxf
110.0 x 110.0 mm

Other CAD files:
Electronics/iRob_ETH/iRob_ETH.f3z
Hardware/iRob_V1_base v19.f3z

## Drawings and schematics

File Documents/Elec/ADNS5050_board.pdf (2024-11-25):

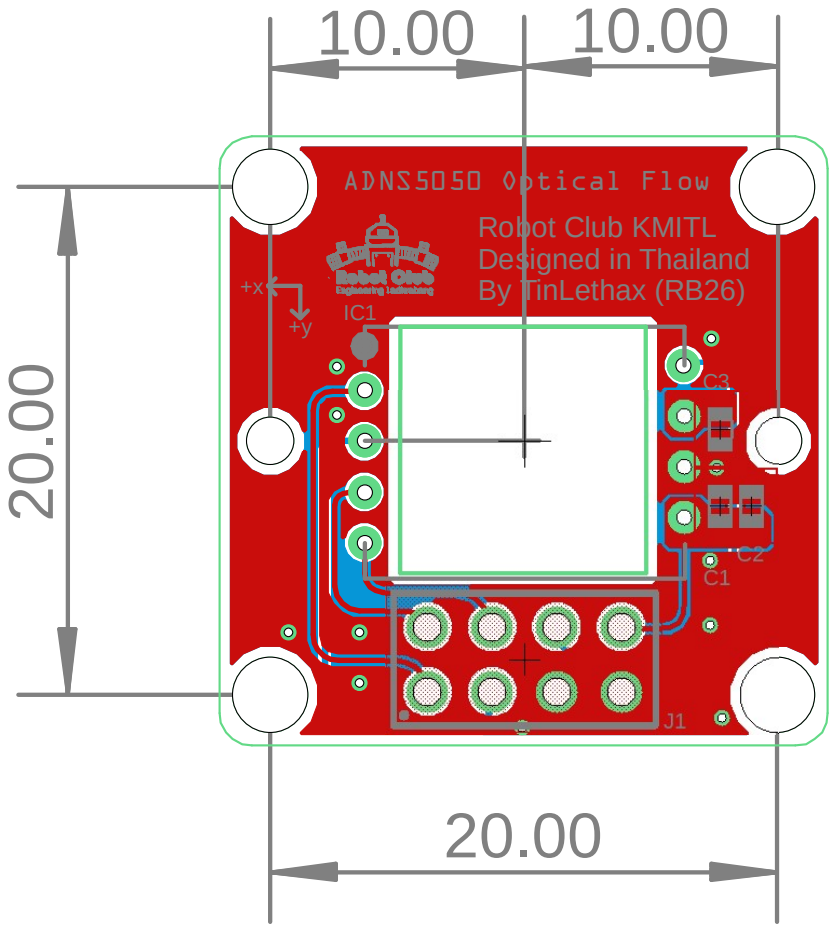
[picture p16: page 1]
ADNS5050 Optical Flow

Robot Club KMITL
Designed in Thailand
By TinLethax (RB26)

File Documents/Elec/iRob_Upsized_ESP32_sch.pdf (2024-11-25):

A

A

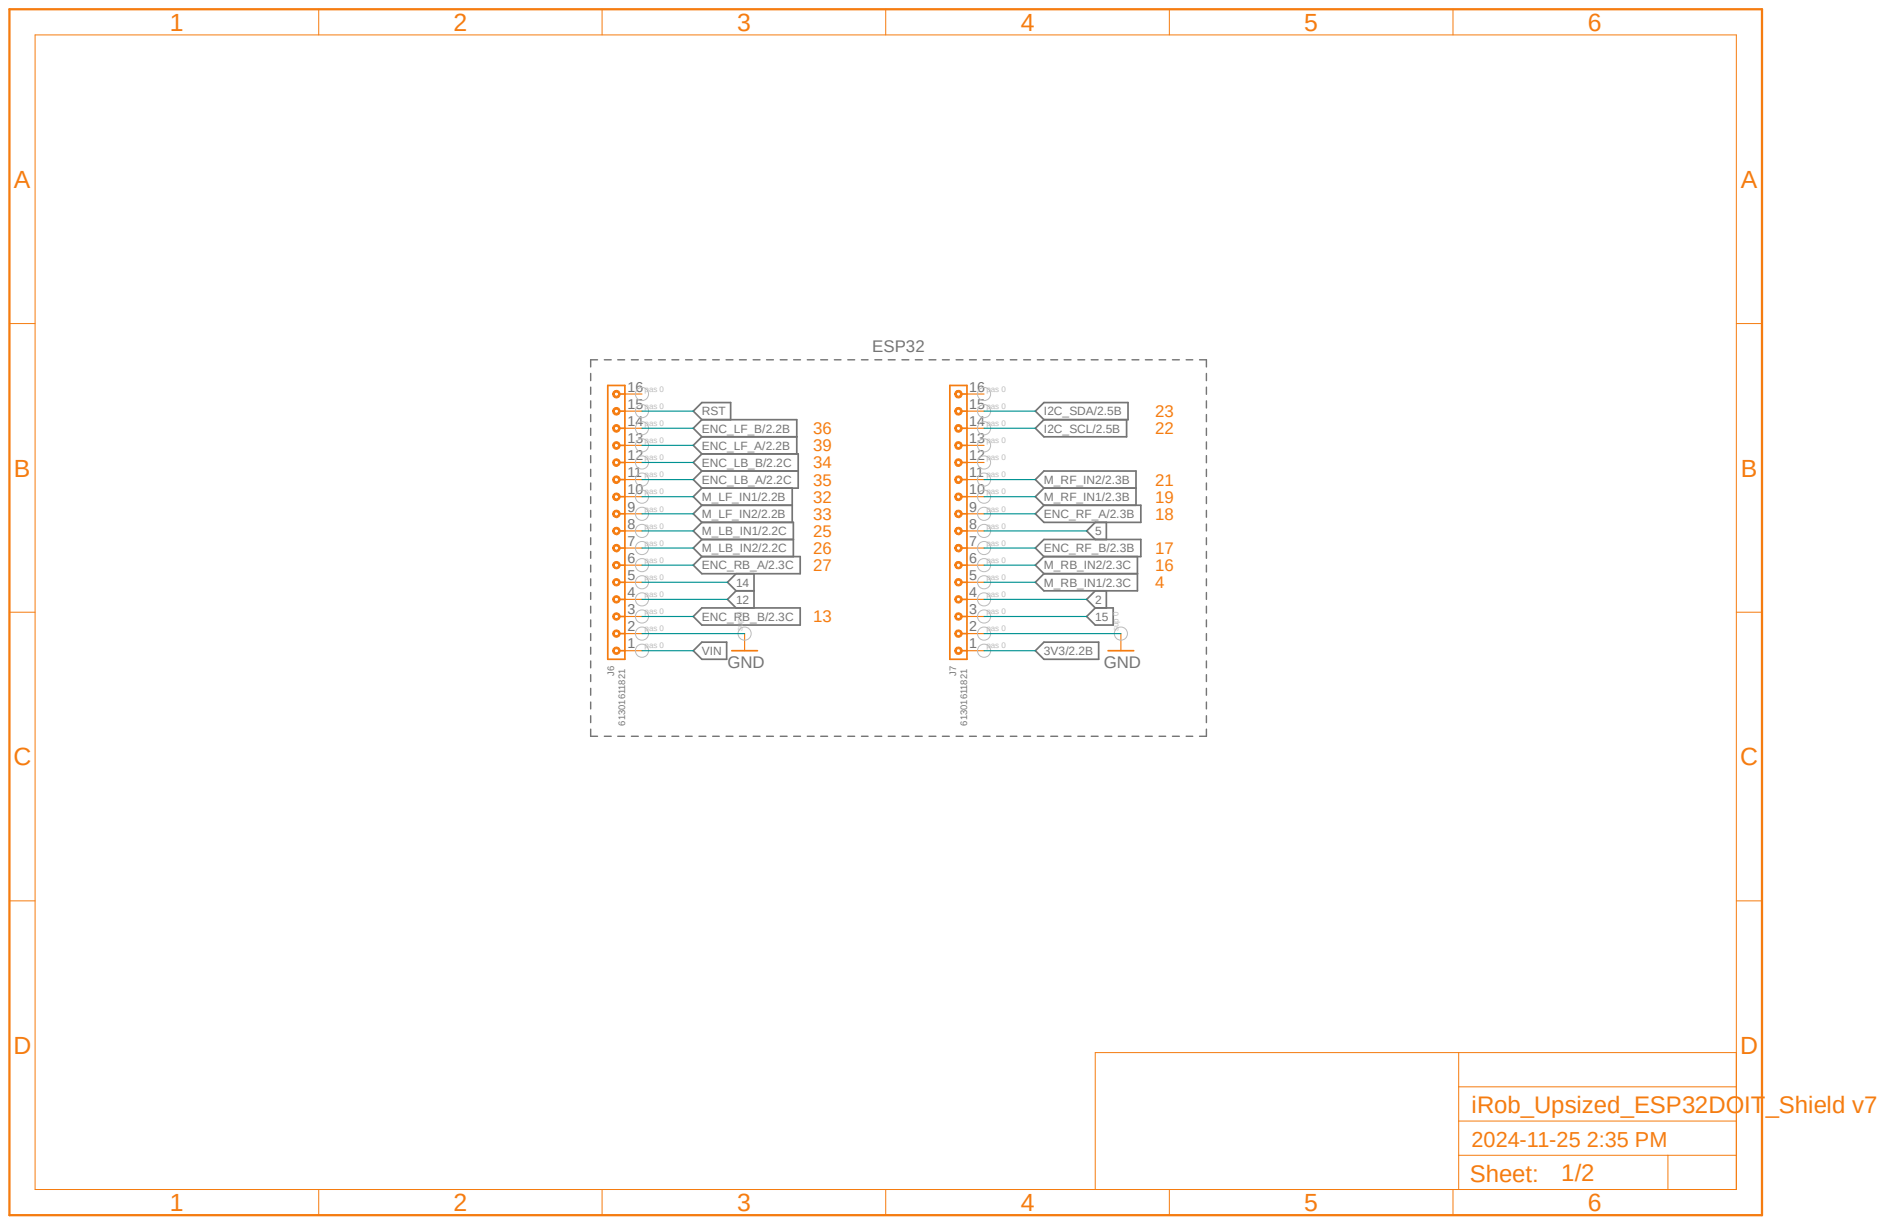
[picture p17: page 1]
ESP32 61301611821; GND; GND J6; VIN; ENC_RB_A/2.3C; ENC_LB_A/2.2C; ENC_LB_B/2.2C; ENC_LF_A/2.2B; ENC_LF_B/2.2B; RST; ENC_RF_B/2.3B; ENC_RF_A/2.3B; I2C_SCL/2.5B; I2C_SDA/2.5B; ENC_RB_B/2.3C; iRob_Upsized_ESP32DOIT_Shield v7; 2024-11-25 2:35 PM Sheet: 1/2; pas 0; pas 0 sup 0; sup 0

A

A

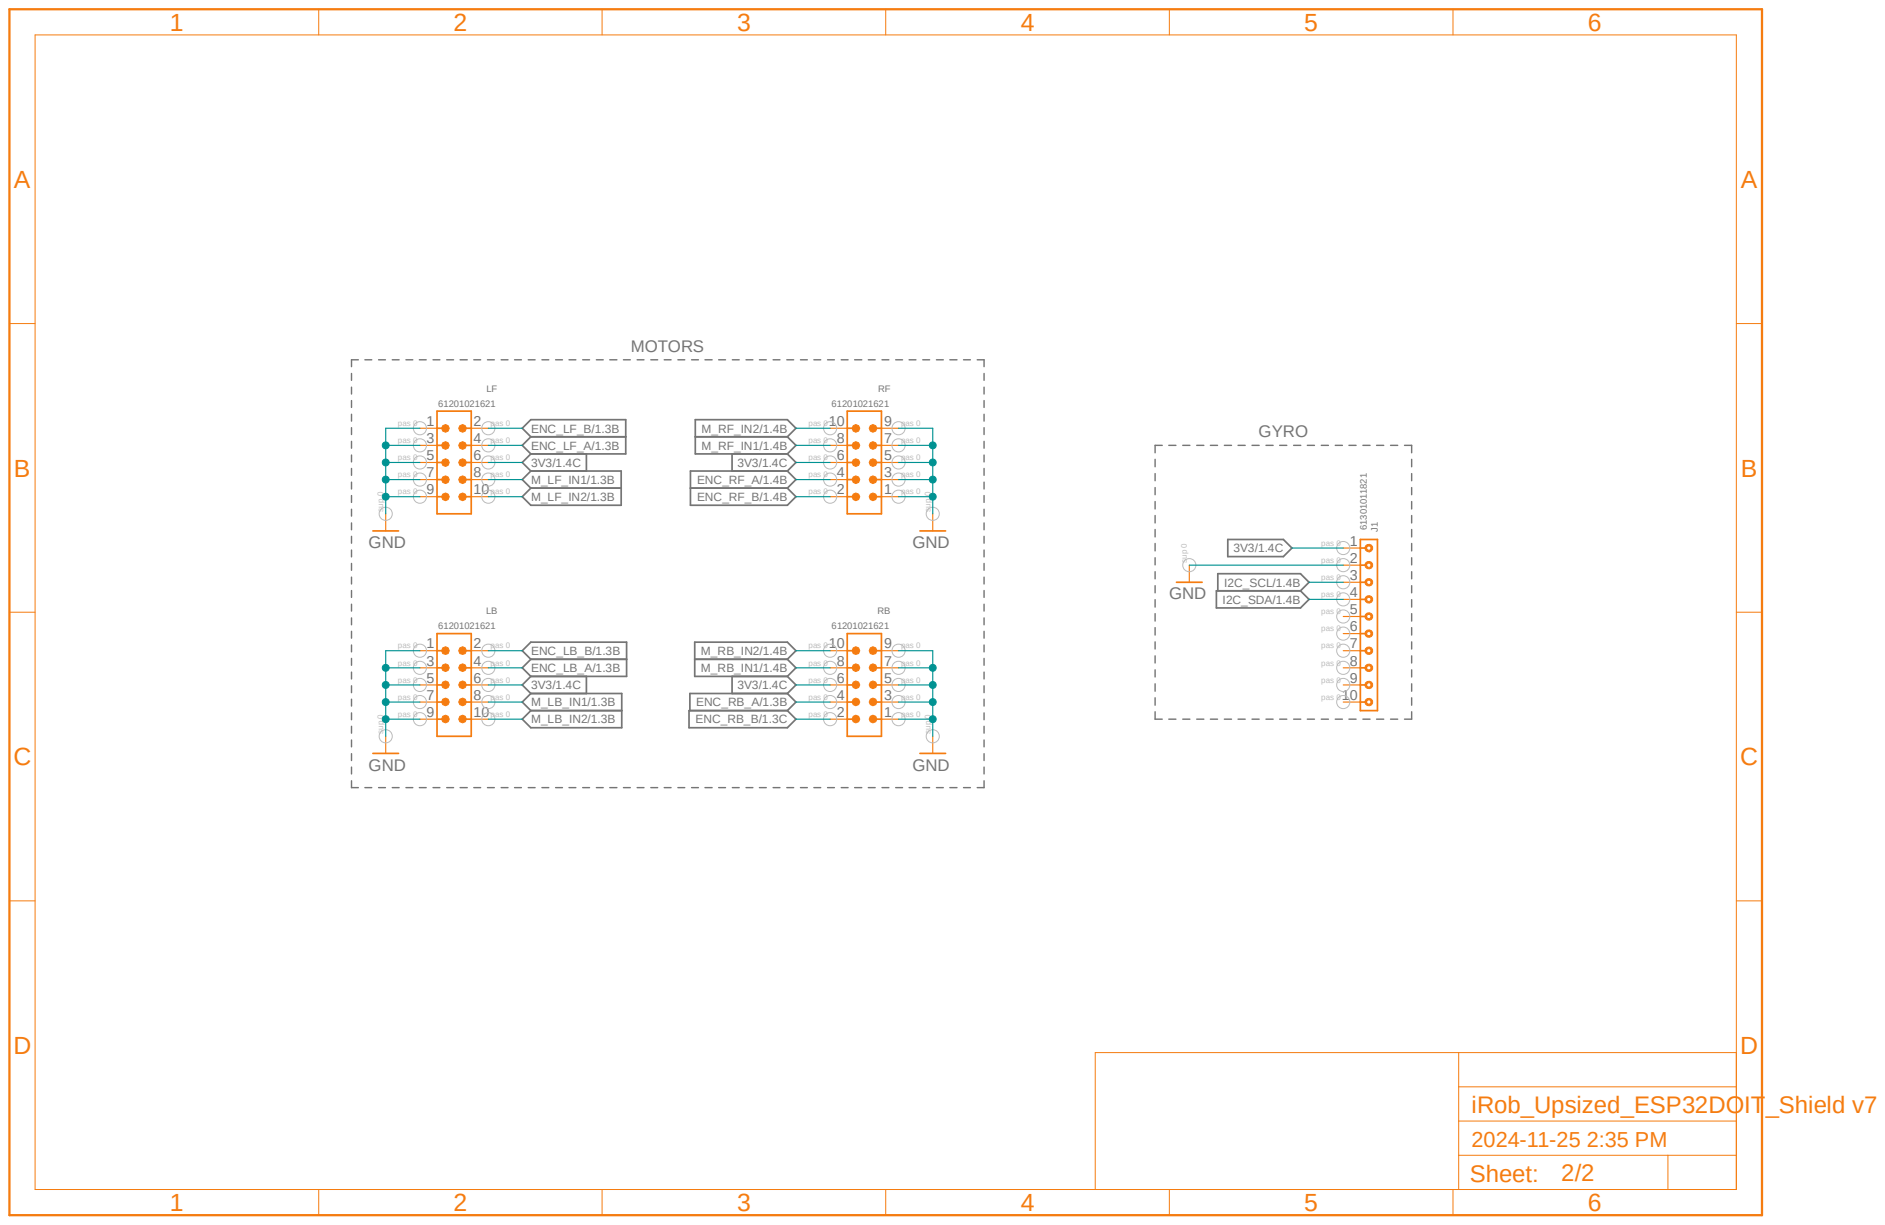
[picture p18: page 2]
MOTORS; GYRO; 61201021621 GND; GND; 10 9 ENC_LF_B/1.3B; ENC_LF_A/1.3B; ENC_LB_B/1.3B ENC_LB_A/1.3B; I2C_SCL/1.4B I2C_SDA/1.4B; ENC_RB_B/1.3C; ENC_RB_A/1.3B; ENC_RF_B/1.4B; ENC_RF_A/1.4B; iRob_Upsized_ESP32DOIT_Shield v7; 2024-11-25 2:35 PM Sheet: 2/2; pas 0; pas 0 sup 0 sup 0; sup 0 sup 0; sup 0

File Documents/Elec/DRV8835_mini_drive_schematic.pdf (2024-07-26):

A

A

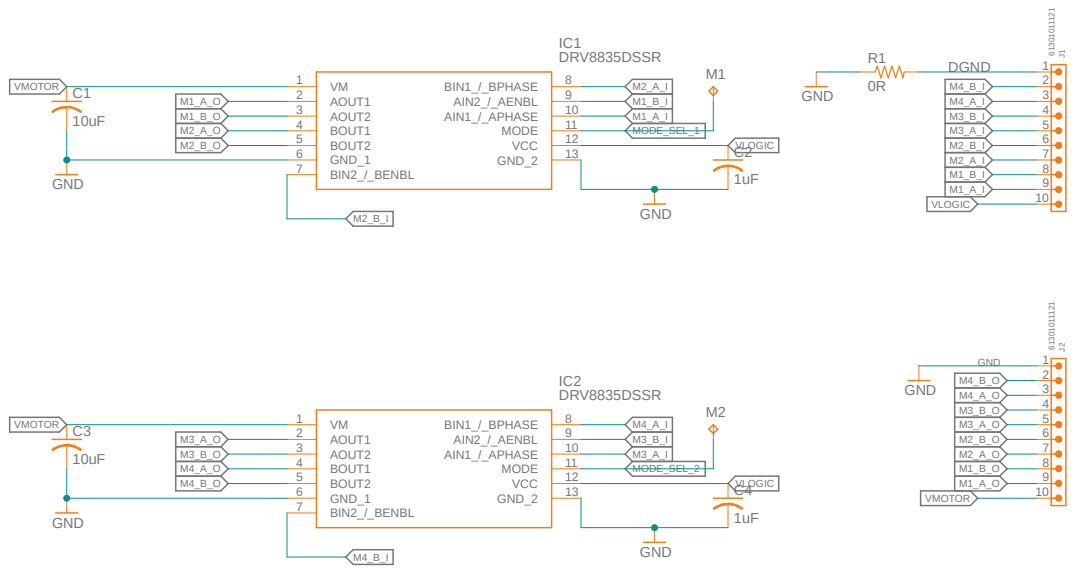
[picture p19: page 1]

DRV8835 Mini drive with up to 8 individual half-bridges Design in Thailand By Tinlethax RB26 Robot Club Engineering KMITL

Sheet: 1/1

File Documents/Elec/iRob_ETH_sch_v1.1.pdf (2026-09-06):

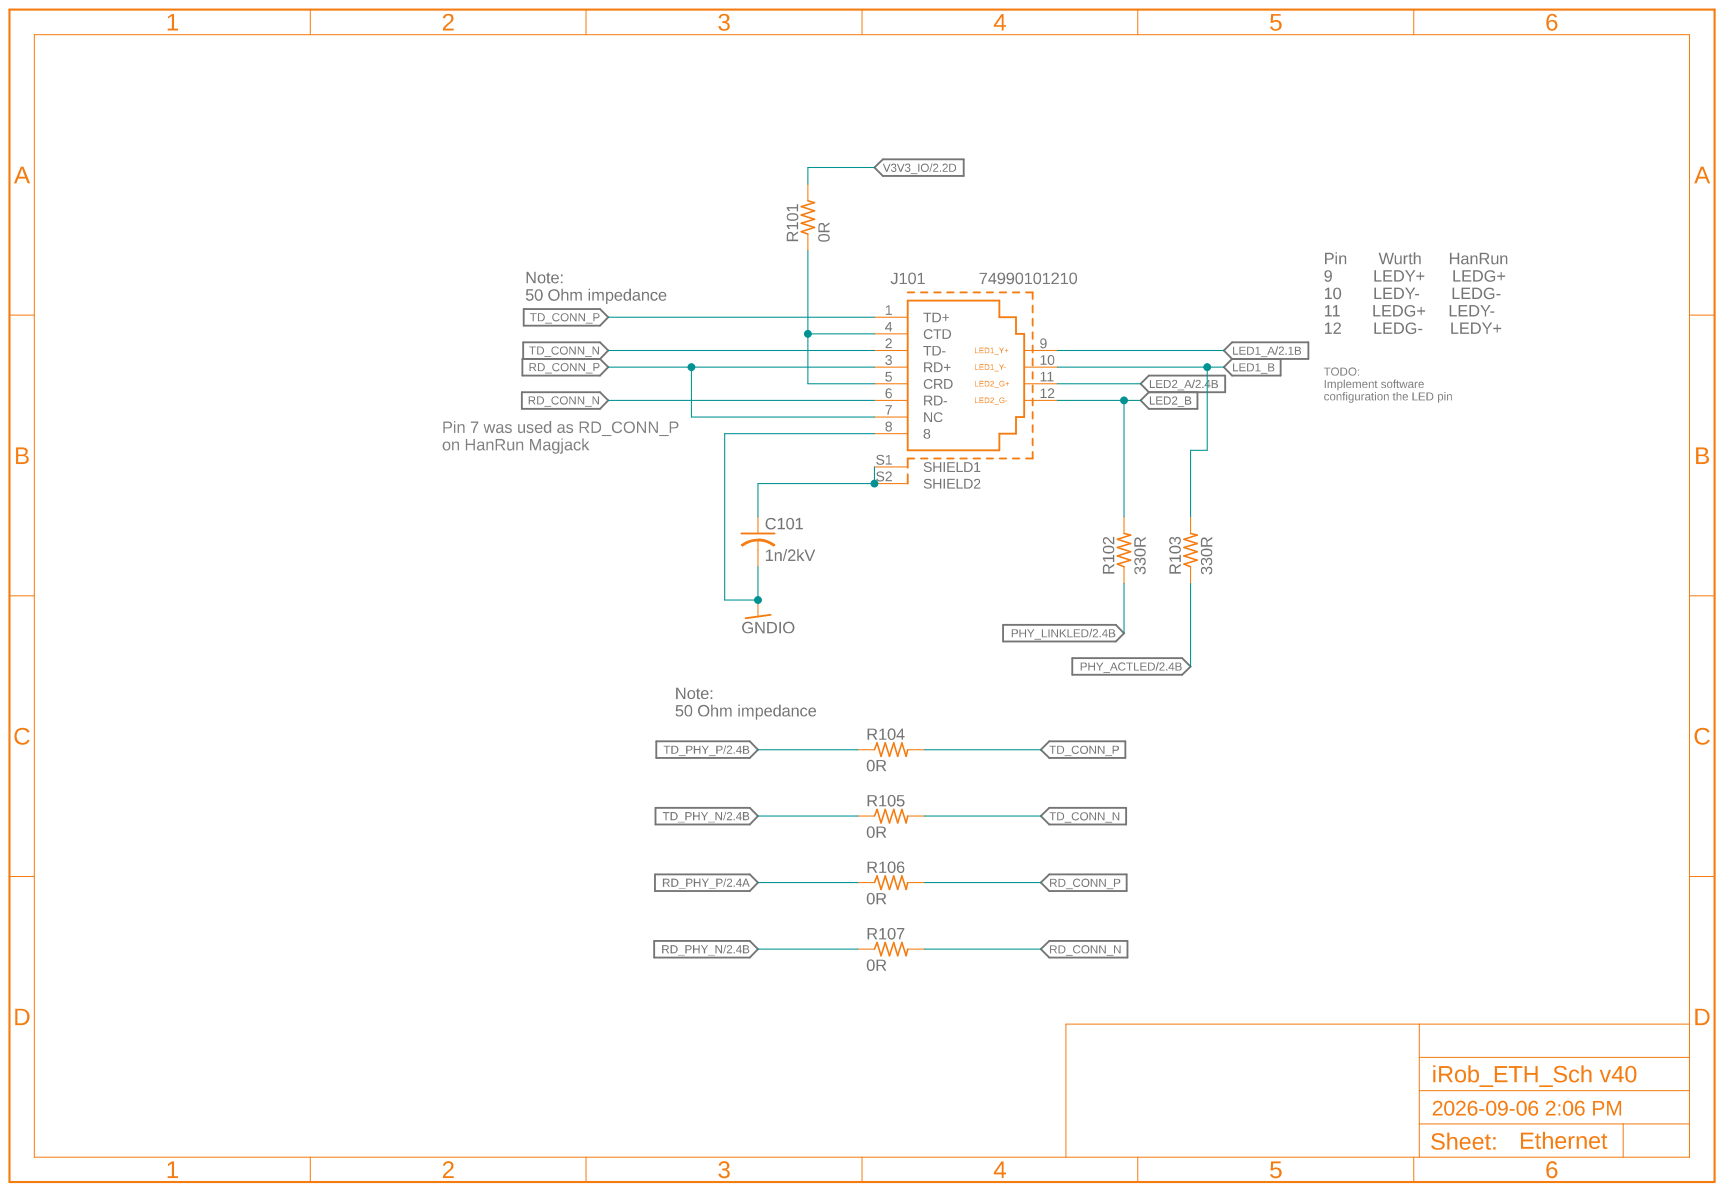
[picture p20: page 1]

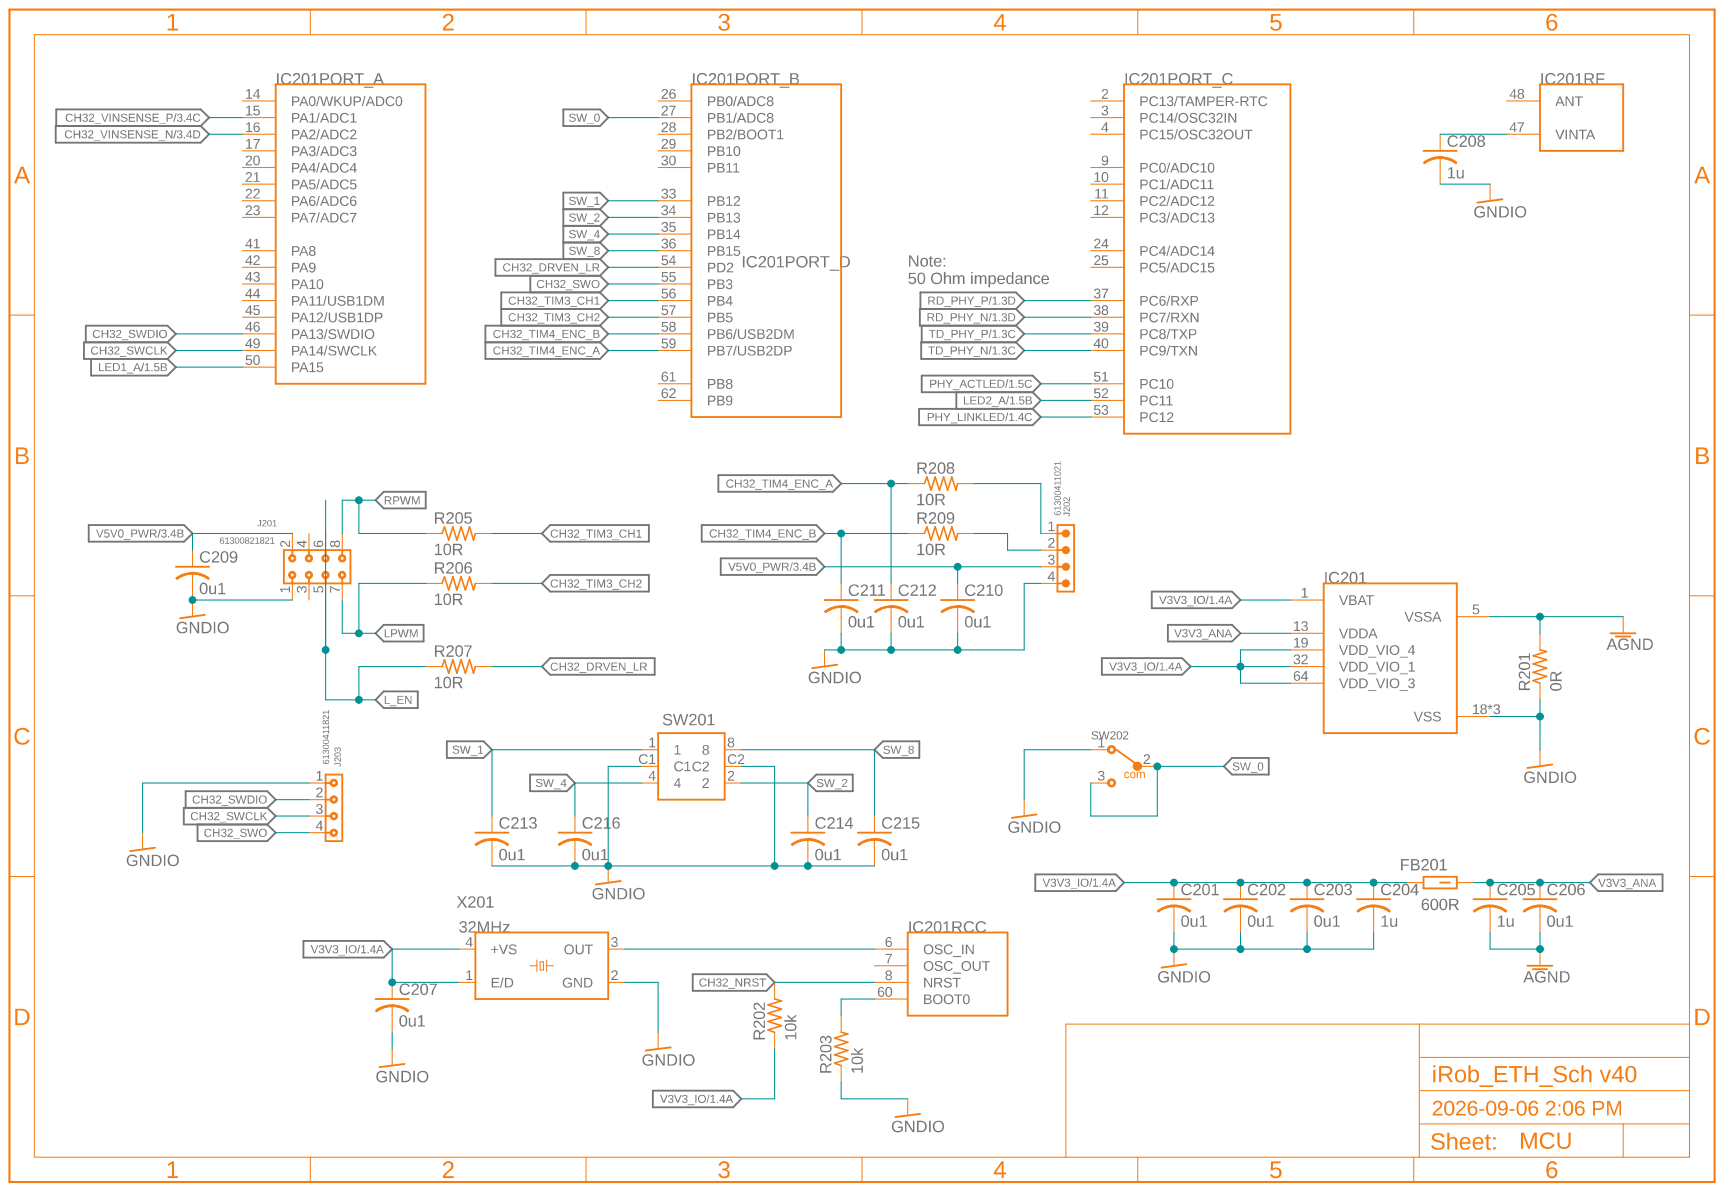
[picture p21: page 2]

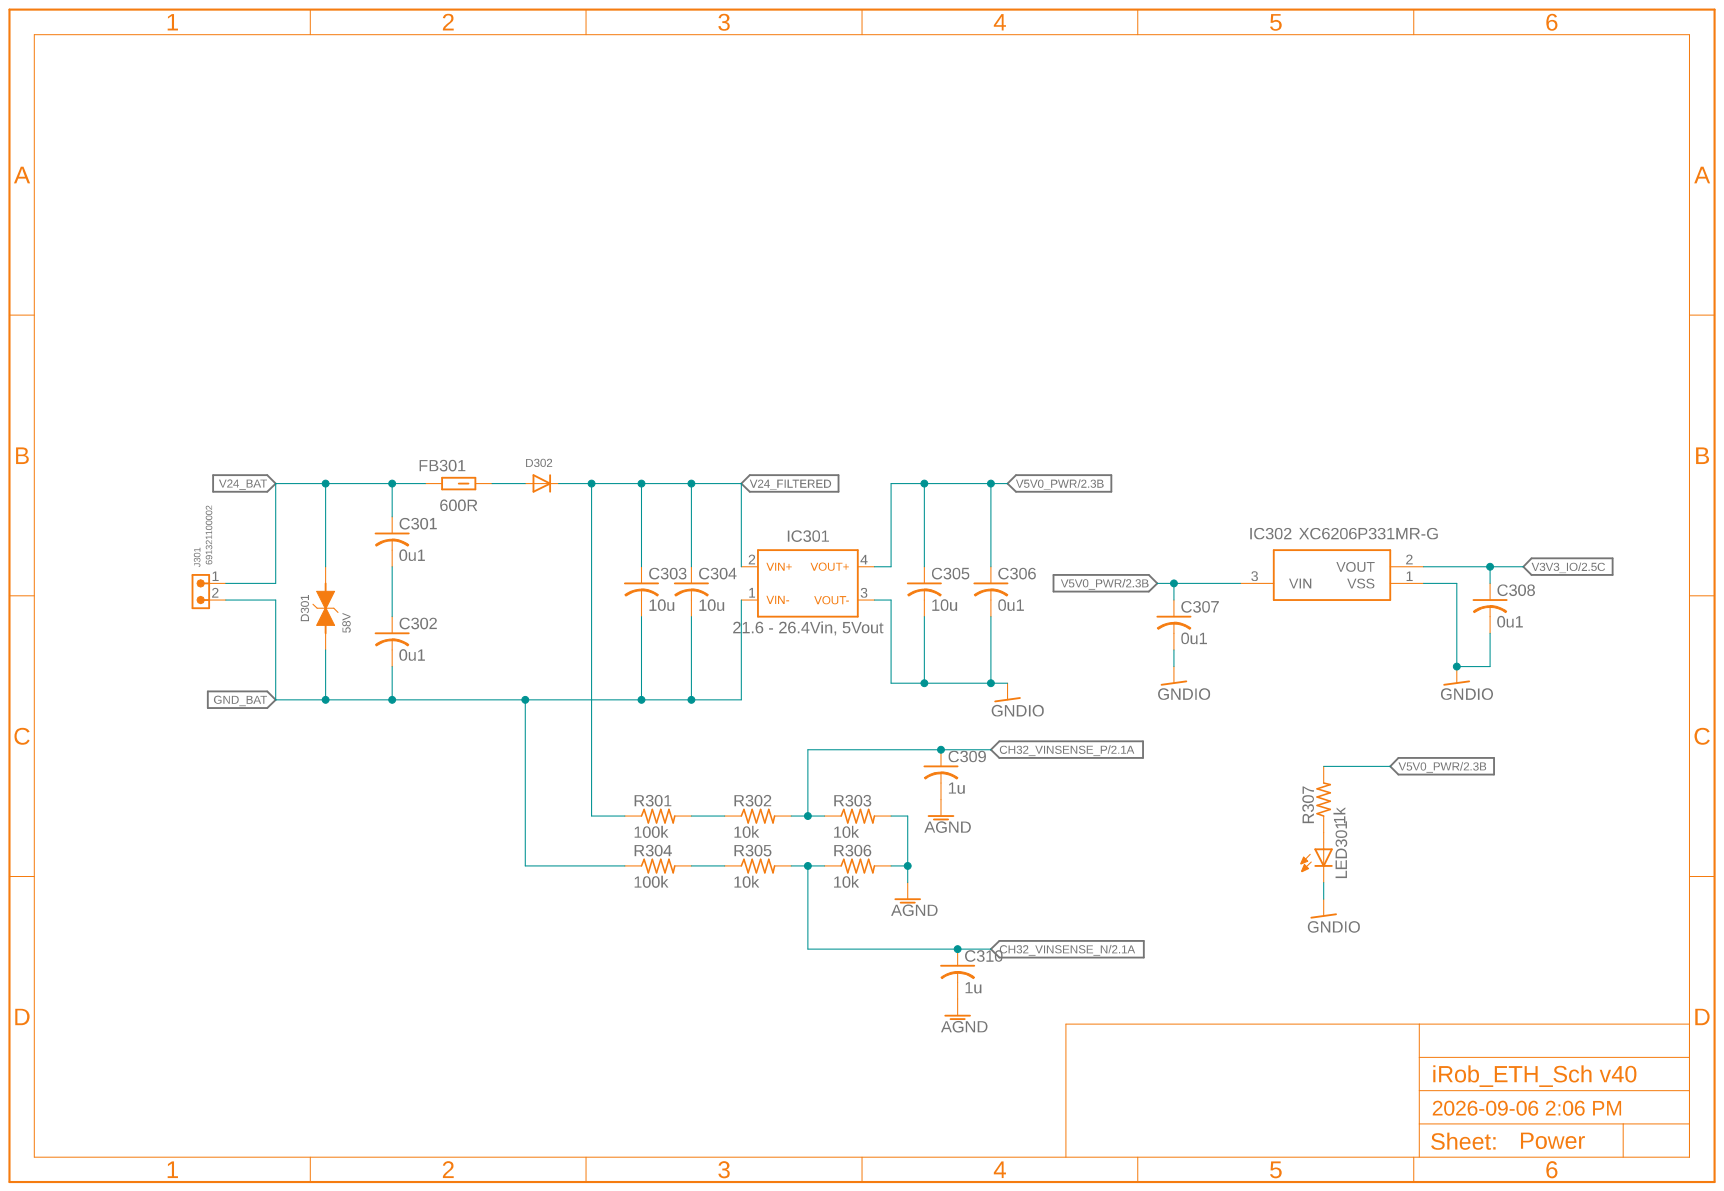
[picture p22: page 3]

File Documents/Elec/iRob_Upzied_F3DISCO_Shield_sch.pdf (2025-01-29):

# 2 J110

## 2 R101

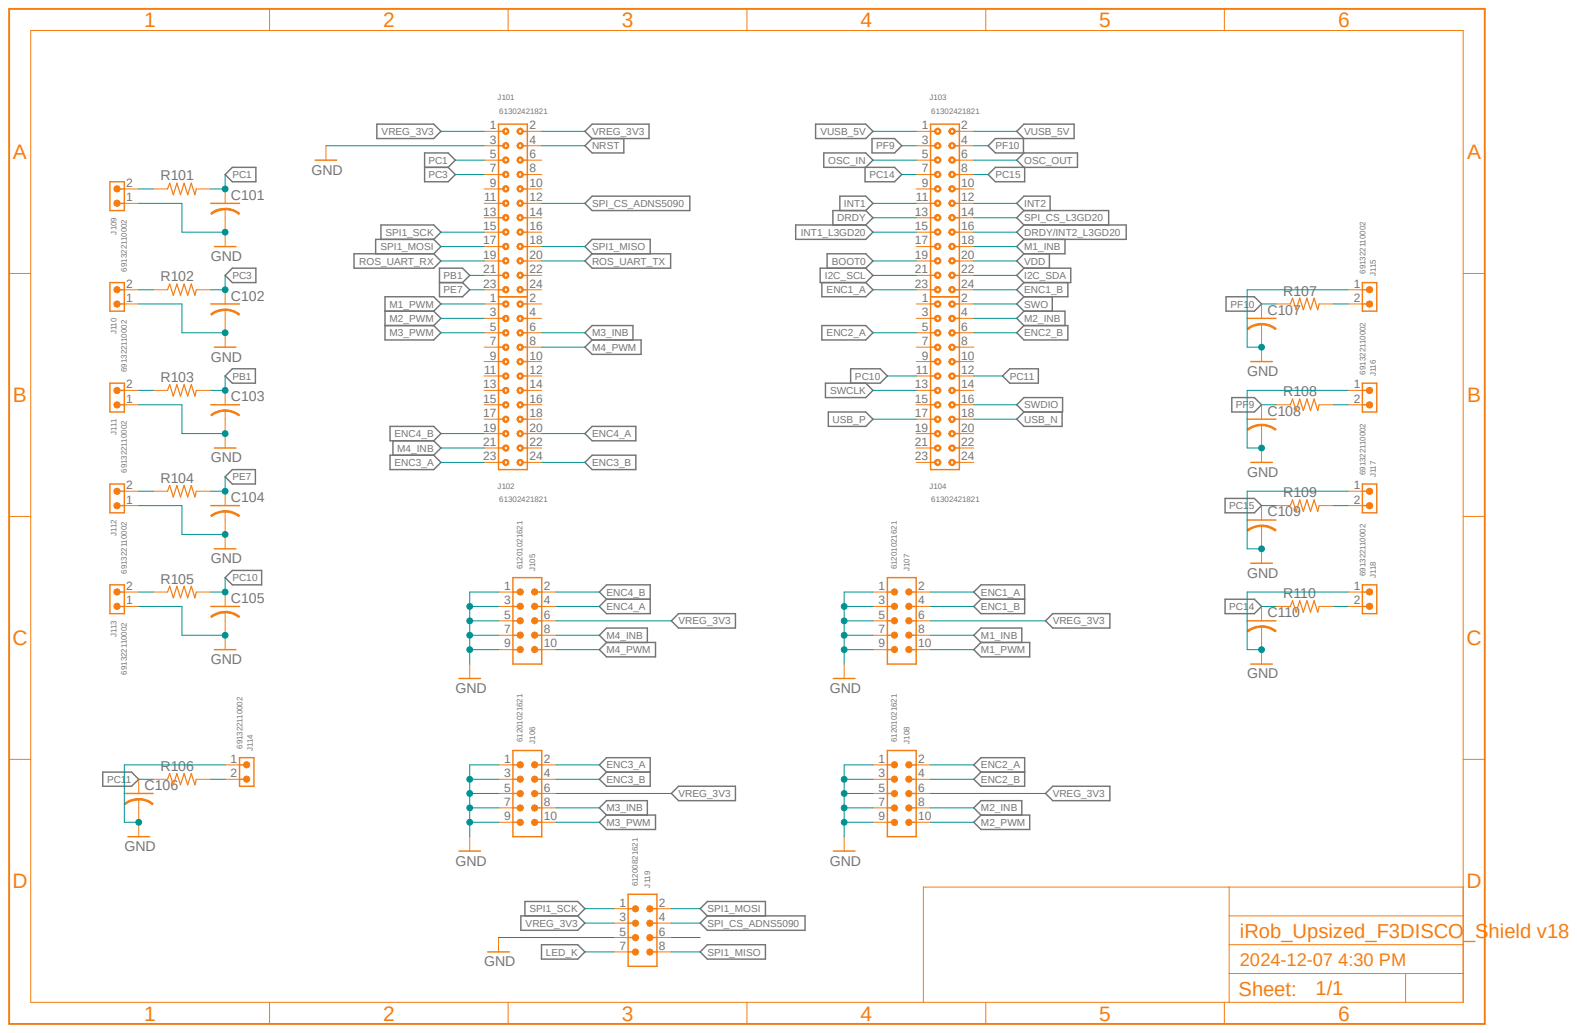
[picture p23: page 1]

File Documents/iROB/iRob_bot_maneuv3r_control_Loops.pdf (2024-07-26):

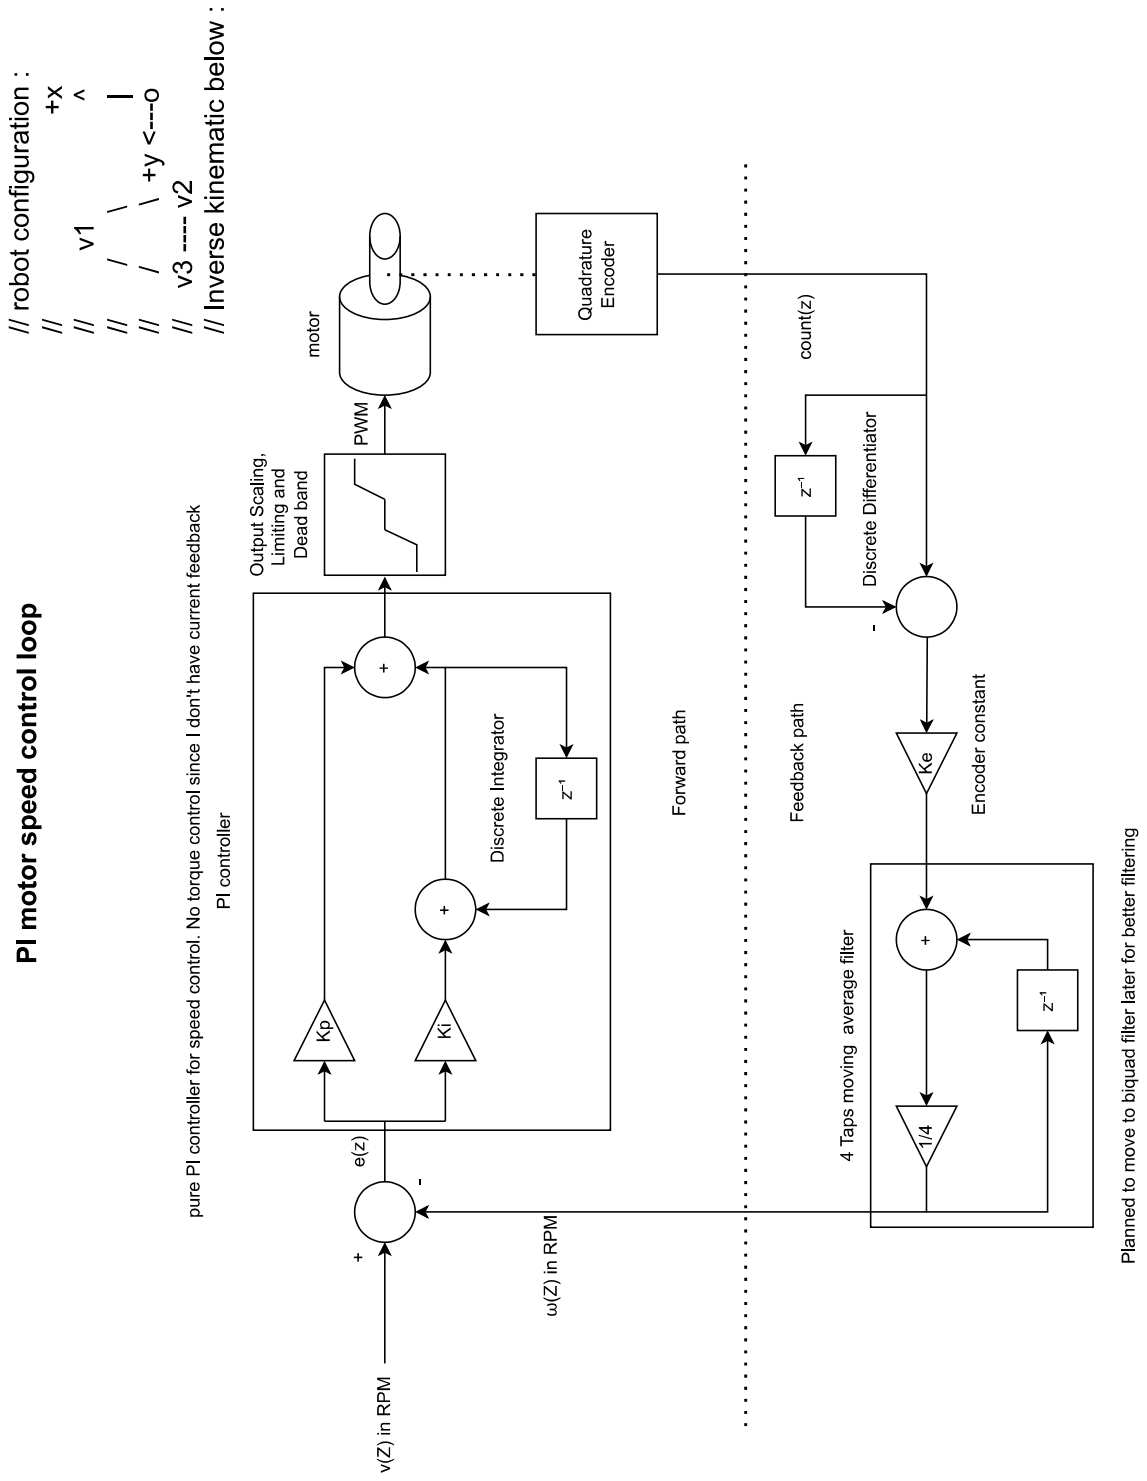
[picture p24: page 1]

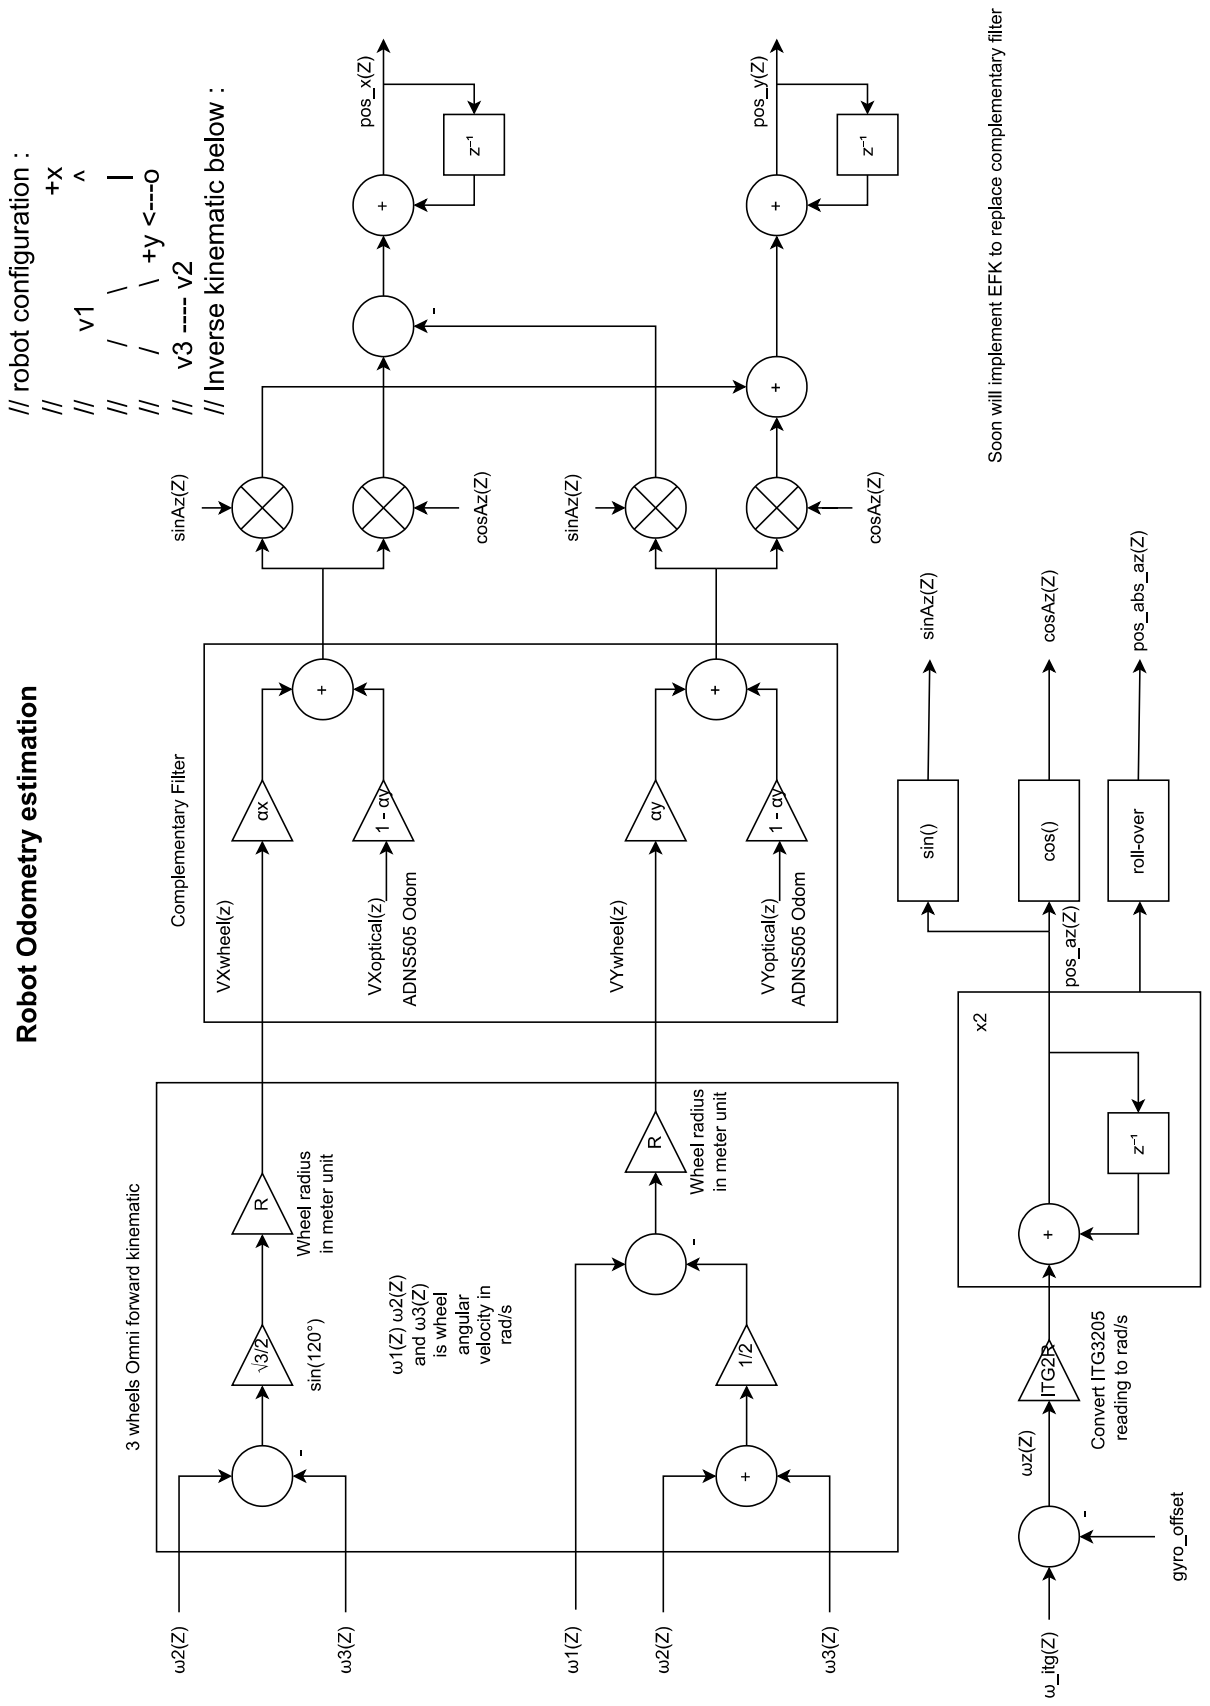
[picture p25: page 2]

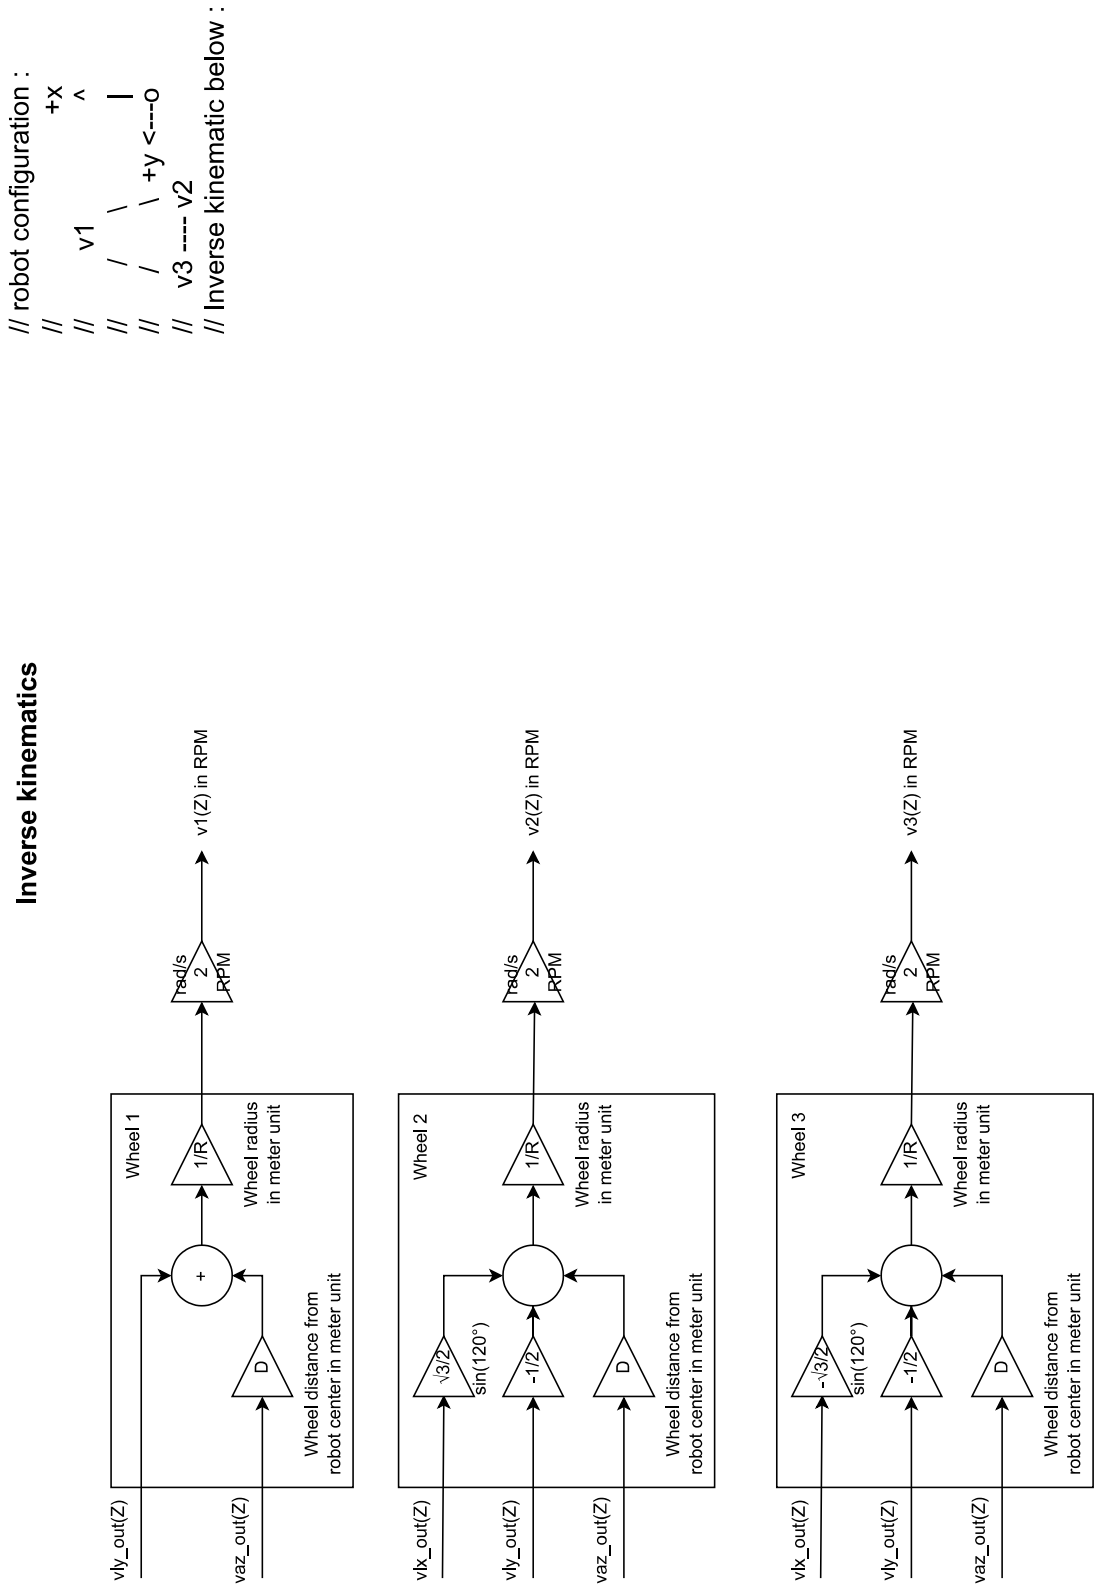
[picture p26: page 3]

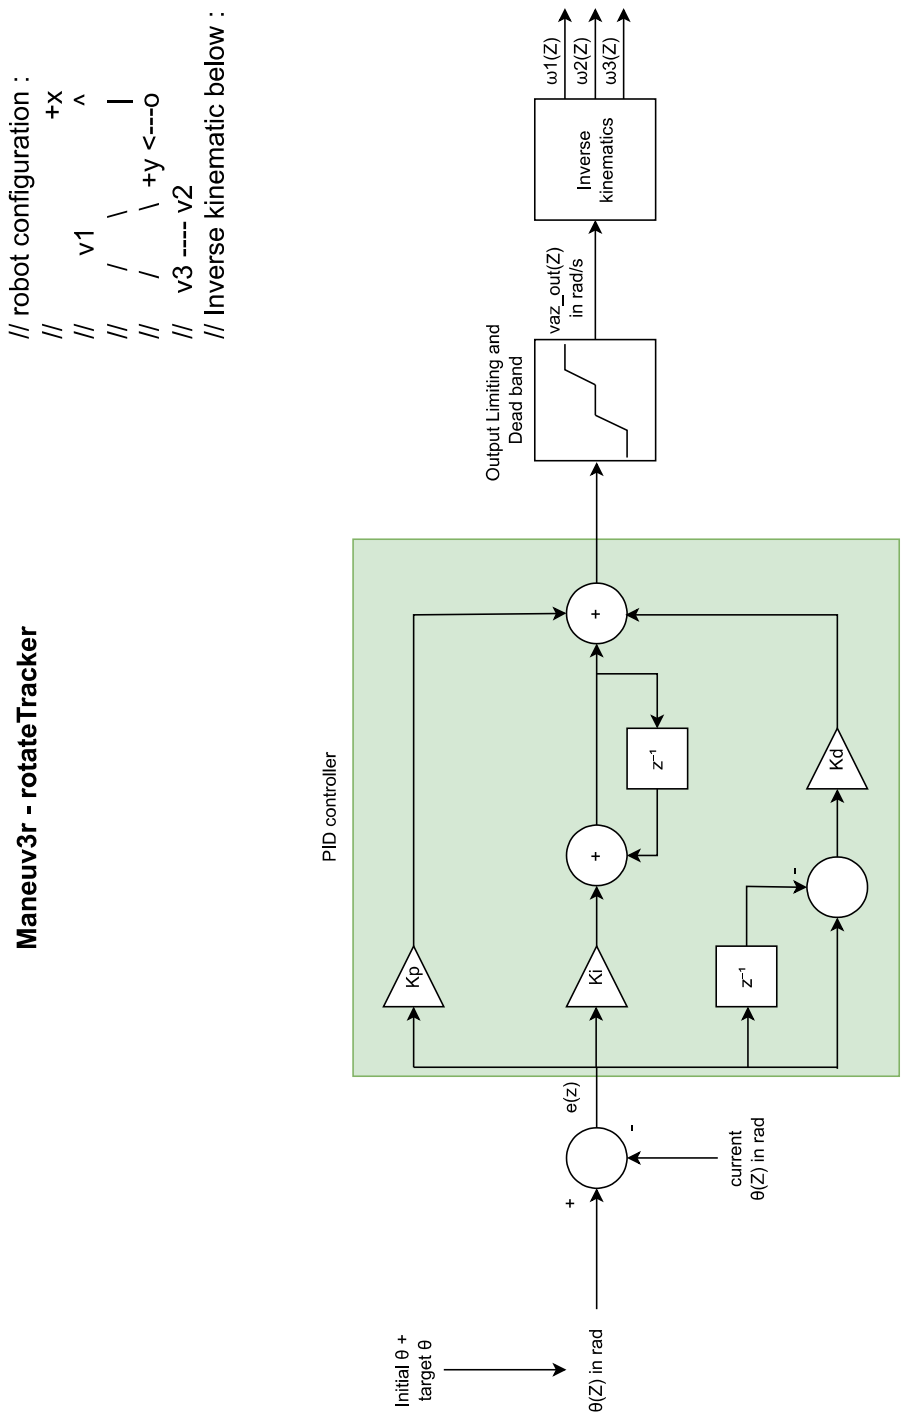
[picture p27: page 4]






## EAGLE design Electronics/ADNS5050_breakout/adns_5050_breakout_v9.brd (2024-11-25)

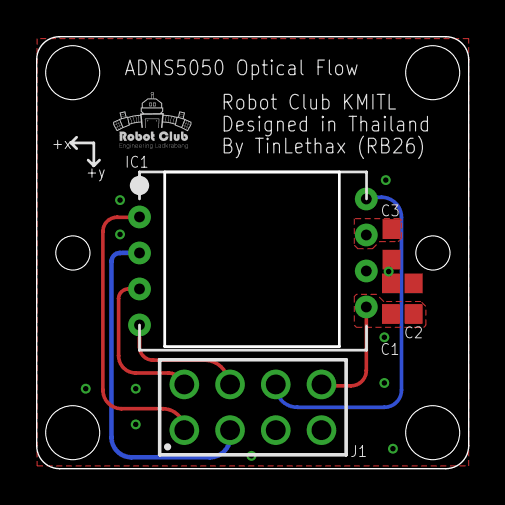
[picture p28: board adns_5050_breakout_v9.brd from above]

Board: 2 copper layers, 24.0 x 24.0 mm, 5 parts (0 on the bottom side), 8 nets.

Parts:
C1, C3: 0.1uF; C0603
C2: 4.7uF; C0603
IC1: ADNS5050; WEIRD_DIP8
J1: 61300821121

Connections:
GND: C1.2, C2.2, C3.2, IC1.P$6, J1.5, J1.7
LED_OD: IC1.P$2, J1.3
NCS: IC1.P$4, J1.4
REGO: C3.1, IC1.P$7
RST: IC1.P$3, J1.2
SCLK: IC1.P$8, J1.6
SDIO: IC1.P$1, J1.1
VCC: C1.1, C2.1, IC1.P$5, J1.8

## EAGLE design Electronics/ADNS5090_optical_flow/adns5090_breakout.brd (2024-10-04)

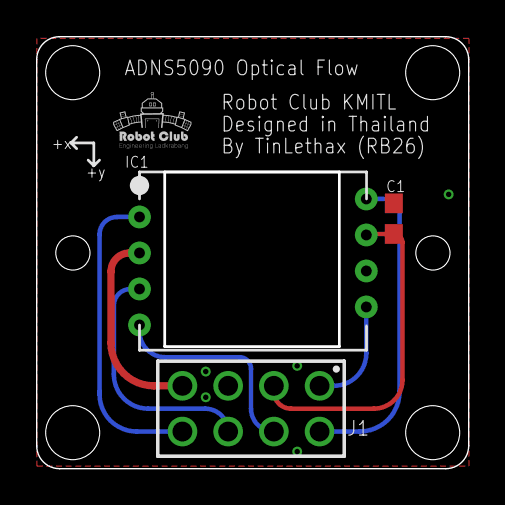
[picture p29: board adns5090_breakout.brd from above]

Board: 2 copper layers, 24.0 x 24.0 mm, 3 parts (0 on the bottom side), 8 nets.

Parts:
C1: 0.1uF; C0603
IC1: ADNS5090; WEIRD_DIP8
J1: 61300821121

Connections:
3V3: C1.1, IC1.P$7, J1.3
/CS: IC1.P$4, J1.4
CLK: IC1.P$5, J1.1
GND: C1.2, IC1.P$6, J1.5
INT: IC1.P$3, J1.6
LED_K: IC1.P$2, J1.7
SI: IC1.P$8, J1.2
SO: IC1.P$1, J1.8

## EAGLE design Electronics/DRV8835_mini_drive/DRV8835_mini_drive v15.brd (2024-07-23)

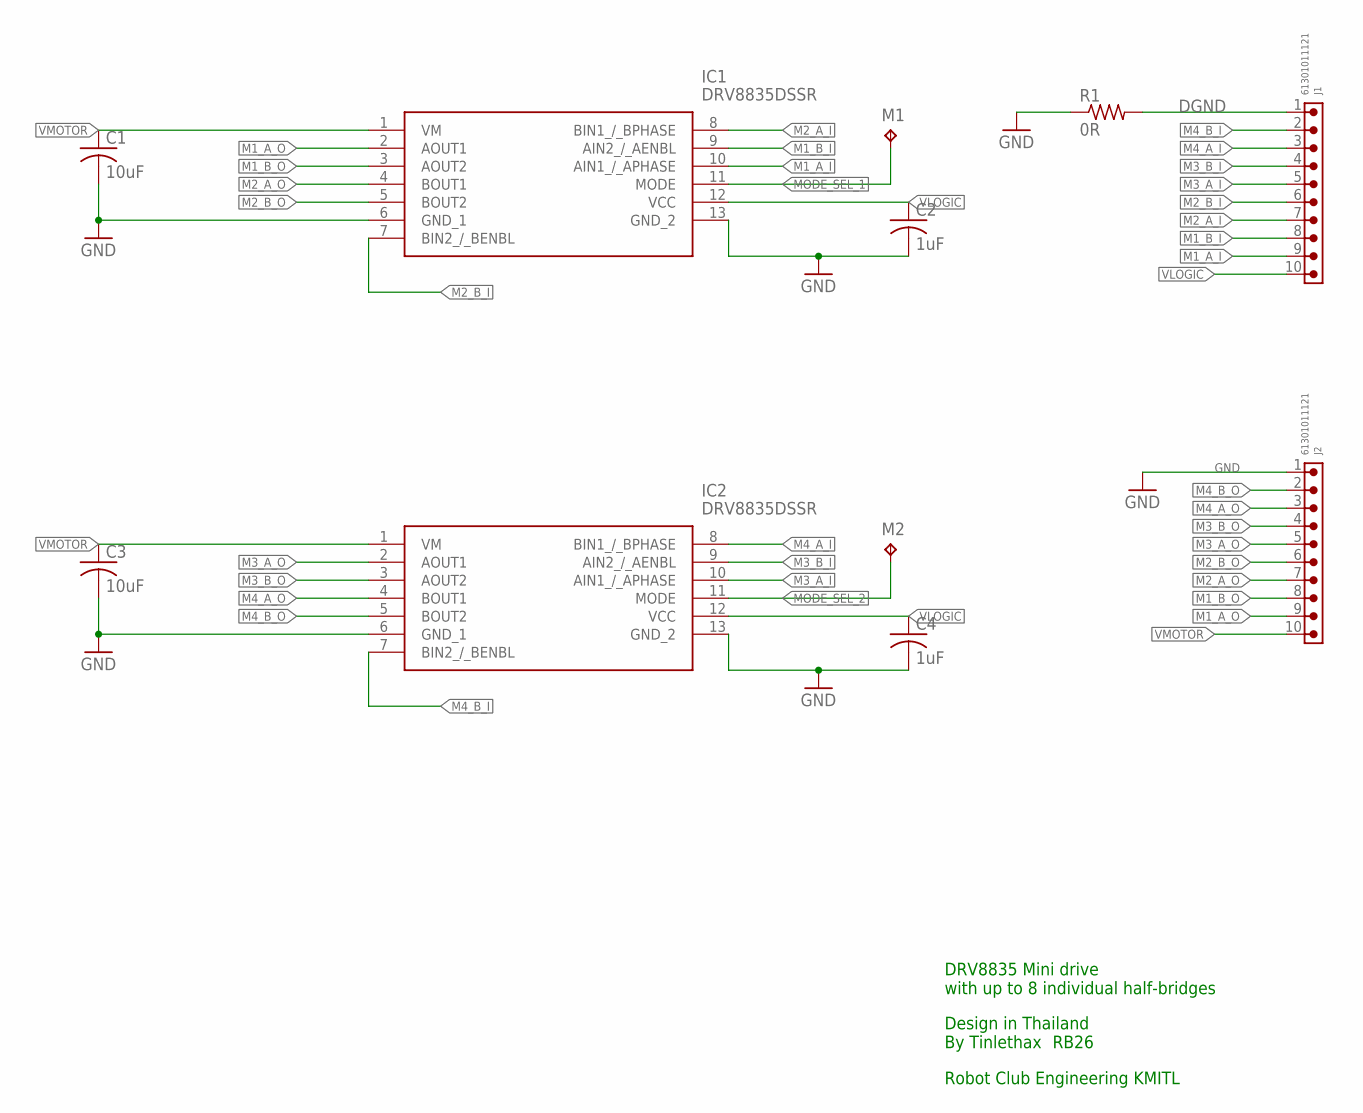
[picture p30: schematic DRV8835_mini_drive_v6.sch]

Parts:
C1, C3: 10uF; C0603
C2, C4: 1uF; C0603
IC1, IC2: DRV8835DSSR
J1, J2: 61301011121
M1, M2: TPTP10SQ; TP10SQ
R1: 0R; R0805

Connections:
DGND: J1.1, R1.2
GND: C1.2, C2.2, C3.2, C4.2, IC1.6 (GND_1), IC1.13 (GND_2), IC2.6 (GND_1), IC2.13 (GND_2), J2.1, R1.1
M1_A_I: IC1.10 (AIN1_/_APHASE), J1.9
M1_A_O: IC1.2 (AOUT1), J2.9
M1_B_I: IC1.9 (AIN2_/_AENBL), J1.8
M1_B_O: IC1.3 (AOUT2), J2.8
M2_A_I: IC1.8 (BIN1_/_BPHASE), J1.7
M2_A_O: IC1.4 (BOUT1), J2.7
M2_B_I: IC1.7 (BIN2_/_BENBL), J1.6
M2_B_O: IC1.5 (BOUT2), J2.6
M3_A_I: IC2.10 (AIN1_/_APHASE), J1.5
M3_A_O: IC2.2 (AOUT1), J2.5
M3_B_I: IC2.9 (AIN2_/_AENBL), J1.4
M3_B_O: IC2.3 (AOUT2), J2.4
M4_A_I: IC2.8 (BIN1_/_BPHASE), J1.3
M4_A_O: IC2.4 (BOUT1), J2.3
M4_B_I: IC2.7 (BIN2_/_BENBL), J1.2
M4_B_O: IC2.5 (BOUT2), J2.2
MODE_SEL_1: IC1.11 (MODE), M1.TP
MODE_SEL_2: IC2.11 (MODE), M2.TP
VLOGIC: C2.1, C4.1, IC1.12 (VCC), IC2.12 (VCC), J1.10
VMOTOR: C1.1, C3.1, IC1.1 (VM), IC2.1 (VM), J2.10

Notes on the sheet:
DRV8835 Mini drive with up to 8 individual half-bridges
Design in Thailand By Tinlethax
Robot Club Engineering KMITL
RB26

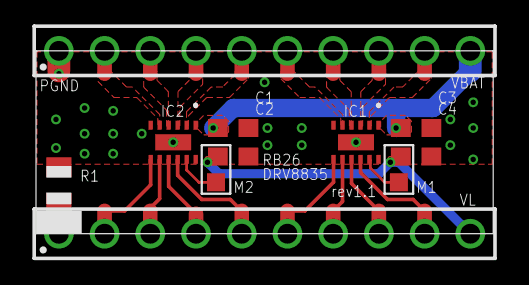
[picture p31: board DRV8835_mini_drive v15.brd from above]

Board: 2 copper layers, 25.4 x 10.2 mm, 11 parts (0 on the bottom side), 22 nets.

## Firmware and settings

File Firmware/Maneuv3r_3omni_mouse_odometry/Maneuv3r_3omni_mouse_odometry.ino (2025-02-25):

#include <Wire.h>
#include "stdirob.h"

// Conversion Constant

// Robot dimension
#define OMNI_WHEEL_D  0.0727f // 72.7mm distance from robot center to wheel center
#define OMNI_WHEEL_R  0.0190f // 19.0mm wheel radius

//#define G1_48 // Select 1:48 gear ratio
#define G1_24 // Select 1:24 gear ratio

#if defined(G1_100)
  #define RAD_S_TO_RPM 954.93f    // rad/s to RPM with 1:100 gearbox scaling for commanding motor 
  #define GEAR_RATIO  0.01f       // 1/100 gearbox ratio
#elif defined(G1_48)
  #define RAD_S_TO_RPM 458.3664f  // rad/s to RPM with 1:48 gearbox scaling for commanding motor 
  #define GEAR_RATIO  0.02083f    // 1/48 gearbox ratio
#elif defined(G1_30)
  #define RAD_S_TO_RPM 318.31f    // rad/s to RPM with 1:30 gearbox scaling for commanding motor
  #define GEAR_RATIO    0.0333f   // 1/30 gearbox ratio
#elif defined(G1_24)
  #define RAD_S_TO_RPM 229.1832f  // rad/s to RPM with 1:24 gearbox scaling for commanding motor 
  #define GEAR_RATIO  0.04166f    // 1/24 gearbox ratio  
#elif defined(G1_20)
  #define RAD_S_TO_RPM  190.9859  // rad/s to RPM with 1:20 gearbox scaling for commanding motor
  #define GEAR_RATIO  0.05f       // 1/20 gearbox ratio
#elif defined(G1_10)
  #define RAD_S_TO_RPM  95.493    // rad/s to RPM with 1:10 gearbox scaling for commanding motor
  #define GEAR_RATIO 0.10f        // 1/10 gearbox ratio
#else
  #error "Please select Gear ratio!"
#endif

// Math constants
#define RPM_TO_RAD_S  0.1047f // 1 rpm == 0.1047 rad/s 
#define OMNI_SINE_120 0.866025f // Sine(120 degree) in rad unit
#define F2_SQRT3      1.1547f // 2/sqrt(3)

// Control system related
#define LOOP_TIME         8 // Loop time is 8ms -> 125Hz

// Odom mouse sensor ADNS5050
#define ADNS5050_SPI_NCS  5
#define ADNS5050_SPI_SIO  19
#define ADNS5050_SPI_SCK  18
#define ADNS5050_NRST     23

// Global Typedef
// Robot odometry and cmd_vel
odometry_t omni_odom;// Robot odometry frame data
odometry_t optical_odom;// Optical odometry (only X and Y vel)
odometry_t wheel_odom;// Wheel odometry (Only X and Y vel)

cmdvel_t omni_cmdvel;// Robot base-link frame velocity command
wheelvel_t omni_wheelvel;// Per-wheel velocity command

TaskHandle_t Core0_t;

// Global variable
unsigned long runner_millis = 0;
unsigned long qcheck_millis = 0;
uint8_t main_fsm = 0;

float atan2pi(float y, float x) {
  float at = atan2(y, x);
  if (at < 0.0)
    at += 6.28319;
  return at;
}

void sensor_Init() {
  /* Begin Sensor Initialization */
  adns5050_init(
    ADNS5050_SPI_NCS,
    ADNS5050_SPI_SIO,
    ADNS5050_SPI_SCK,
    ADNS5050_NRST
  );
  // Probe for sensor
  if (adns5050_Probe()) {
    Serial.println("ADNS 5050 probing error!");
    while (1);
  }
  // Set CPI 
  adns5050_setcpi();
  // turn LED on
  adns5050_setLED();
  
  // Start I2C
  Wire.begin();

  // Init magnetometer
  //hmc5883l_init();

  // Init Gyro
  itg3205_init();

  // Init HLS_LFCD2 LiDAR
  hls_initLiDAR();
  /* end Sensor Initialization */
}

void task_Init(){
  
  xTaskCreatePinnedToCore(
      loop0, /* Function to implement the task */
      "network", /* Name of the task */
      40000,  /* Stack size in words */
      NULL,  /* Task input parameter */
      0,  /* Priority of the task */
      &Core0_t,  /* Task handle. */
      0); /* Core where the task should run */  
        
}

uint16_t poseIndex;
poseArray pose0[]={
  {0.50, 0.21, -1.570796},
  {0.0, 0.46, 1.570796},
  {0.0, 0.00, 0.0}
};

//poseArray pose0[]={
//  {0.5, 0.0, -1.570796},
//  {0.50, 0.50, 0},
//  {0.0, 0.50, 1.570796},
//  {0.0, 0.0, 0.0}
//};

//poseArray pose0[]={
//  {0.9, 0.0, 0.0},
//  {0.9, 0.9, 0.0},
//  {0.0, 0.9, 0.0},
//  {0.0, 0.0, 0.0}
//};

void setup() {
  // put your setup code here, to run once:
  motor_omniInit(&omni_wheelvel);// Pass the pointer to Wheel velocity command
  Serial.begin(115200);
  task_Init();

  pinMode(2, OUTPUT);
  pinMode(0, INPUT);
  while(digitalRead(0));
  Serial.println("Initializing...");
  digitalWrite(2, HIGH);
  // Init encoder
  encoder_Init();// Initialize ESP32 Encoder interrupt.
  delay(200);
  sensor_Init();
  digitalWrite(2, LOW);
  Serial.println("Done!");

  // Initialize fuser
  fuser_Init(
    &omni_odom,   // Robot's odometry
    0.0,        // Filter weight of the wheel odom (vel_x) 0.625
    0.0,        // Filter weight of the wheel odom (vel_y) 0.625
    1.0          // Filter weight of the gyro angular velocity (vel_az)
  );
  
  /* Begin maneuv3r algorithm */
  maneuv3r_init(
    &omni_odom, // Robot's system-wide odometry
    &omni_cmdvel // Robot's system-wide cmd_vel
    );
  maneuv3r_pidInit(
    2.0, 0.001, 0.001,   // Walk kPID Kp 2.5 Ki 0.003 Kd 0.0
    0.005, 0.45,        // Walk min and max velocity (m/s)

    0.5, 0.12, 0.0  // Twizzle rotate kPID Kp 0.86 Ki 0.00085 Kd 0.003
  );

  maneuv3r_update_Cmdvel(0.0, 0.0, 0.0);
  /* End maneuv3r algorithm */
}

inline void computeOdom() {
  encoder_doVel();// Estimate Wheel RPM.

  // Re-using the optical and wheel odometry struct.
  itg3205_getPosZ(&optical_odom);       // Integrate the angular velocity to estimate orientation.
  //hmc5883l_getPosZ(&wheel_odom);        // Update robot orientation (az) referenced to north, also update angular velocity.
  fuser_processYaw(&optical_odom, &wheel_odom);// Fuse Gyro angular vel with Mag angular vel.
  
  adns5050_updateVel(&optical_odom);// Get X and Y velocity from mouse sensor.
  odometry_wheelOdom(&wheel_odom);  // Get X and Y velocity from wheel encoders.
  fuser_processOdom(&optical_odom, &wheel_odom); // Fuse Optical flow odom with Wheel odom.

  odometry_posUpdate(&omni_odom);// Update robot X, Y position by integrating vx and vy.
}


// robot configuration :
//                    +x
//        v1           ^
//       /  \          |
//      /    \  +y <---o
//    v3 ---- v2
// Inverse kinematic below :
inline void cmd_vel(cmdvel_t *command_vel) {
  omni_wheelvel.v1 =
    (command_vel->vly_out +
     (command_vel->vaz_out * OMNI_WHEEL_D)
    ) / OMNI_WHEEL_R;

  omni_wheelvel.v2 =
    ((command_vel->vlx_out * OMNI_SINE_120) +
     (command_vel->vly_out * -0.5) +
     (command_vel->vaz_out * OMNI_WHEEL_D)
    ) / OMNI_WHEEL_R;

  omni_wheelvel.v3 =
    ((command_vel->vlx_out * -OMNI_SINE_120) +
     (command_vel->vly_out * -0.5) +
     (command_vel->vaz_out * OMNI_WHEEL_D)
    ) / OMNI_WHEEL_R;

  omni_wheelvel.v1 *= RAD_S_TO_RPM;
  omni_wheelvel.v2 *= RAD_S_TO_RPM;
  omni_wheelvel.v3 *= RAD_S_TO_RPM;

  motor_pidUpdate();// Do motor PID algorithm
}
uint8_t play_cnt = 0;
float circle = 0.0;
void robot_runner() {

  switch (main_fsm) {
    case 0:
      {
        main_fsm = 1;
//        if (maneuv3r_twizzlesTrackerAbs(
//            pose0[poseIndex].px,
//            pose0[poseIndex].py,
//            pose0[poseIndex].tz
//          )
//        ) {
//          poseIndex++;
//          if(poseIndex == (sizeof(pose0) / 12)){
//            poseIndex = 0;
//            main_fsm = 255;
//          }
//        }
      }
      break;
      
      break;

    case 1:
    {
        if (maneuv3r_twizzlesTrackerAbs(
            cos(circle) * 0.5,
            sin(circle) * 0.5,
            0.0
          )
        ) {
          circle += 0.349066;
        }
    }
    break;

    case 255:
      {

      }
      break;
  }

}
void loop() {
  //Control loop here
  if ((micros() - runner_millis) > LOOP_TIME * 1000) {
    runner_millis = micros();
    computeOdom();
    robot_runner();
    cmd_vel(&omni_cmdvel);
  }
}

void loop0(void *pvParameters){
  
  while(1){
     Serial.print("Px:");
     Serial.print(omni_odom.pos_x);
     Serial.print("\tPy:");
     Serial.println(omni_odom.pos_y);
     Serial.print("Vx:");
     Serial.print(omni_odom.vel_x);
     Serial.print("\tVy:");
     Serial.println(omni_odom.vel_y);
     delay(100);
  }
}

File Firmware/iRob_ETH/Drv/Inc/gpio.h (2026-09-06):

#ifndef GPIO_H
#define GPIO_H

#include "ch32f20x.h"
#include "ch32f20x_rcc.h"
#include "ch32f20x_gpio.h"

void vGpio_initPins(void);


// PORT-A

#define GPIO_PA1_VINSENSE_P		GPIO_Pin_1
#define GPIO_PA2_VINSENSE_N		GPIO_Pin_2
#define GPIO_PA15_LED1_A		GPIO_Pin_15

// PORT-B
#define GPIO_PB1_SW_0			GPIO_Pin_1
#define GPIO_PB4_TIM3_CH1		GPIO_Pin_4
#define GPIO_PB5_DRV_POL		GPIO_Pin_5
#define GPIO_PB6_TIM4_ENC_B		GPIO_Pin_6
#define GPIO_PB7_TIM4_ENC_A		GPIO_Pin_7
#define GPIO_PB12_SW_1			GPIO_Pin_12
#define GPIO_PB13_SW_2			GPIO_Pin_13
#define GPIO_PB14_SW_4			GPIO_Pin_14
#define GPIO_PB15_SW_8			GPIO_Pin_15

// PORT-C 
#define GPIO_PC6_RD_PHY_P		GPIO_Pin_6
#define GPIO_PC7_RD_PHY_N		GPIO_Pin_7
#define GPIO_PC8_TD_PHY_P		GPIO_Pin_8
#define GPIO_PC9_TD_PHY_N		GPIO_Pin_9
#define GPIO_PC10_ACTLED		GPIO_Pin_10
#define GPIO_PC11_LED2_A		GPIO_Pin_11
#define GPIO_PC12_LINKLED		GPIO_Pin_12

// PORT-D
#define GPIO_PD2_DRVEN			GPIO_Pin_2

#define DRVEN_ON				GPIO_WriteBit(GPIOD, GPIO_PD2_DRVEN, Bit_SET)
#define DRVEN_OFF				GPIO_WriteBit(GPIOD, GPIO_PD2_DRVEN, Bit_RESET)
	
#define DRV_H					GPIO_WriteBit(GPIOB, GPIO_PB5_DRV_POL, Bit_SET)
#define DRV_L					GPIO_WriteBit(GPIOB, GPIO_PB5_DRV_POL, Bit_RESET)

void vGpio_initPins(void);
uint8_t vGpio_readIPConfigPins(void);
void vGpio_setLinkLed(uint8_t mode);
void vGpio_setActLed(uint8_t mode);
void vGpio_ledToggleTask(void);


#endif

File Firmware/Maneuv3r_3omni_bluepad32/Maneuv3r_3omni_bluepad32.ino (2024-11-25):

#include <Bluepad32.h>
#include <uni.h>
#include <Wire.h>

#include "maneuv3r.h"
#include "stdodom.h"

//#define IROB_UPSIZED

// Conversion Constant

// Robot dimension
#ifndef IROB_UPSIZED
  #define OMNI_WHEEL_D  0.0727f // 72.7mm distance from robot center to wheel center
  #define OMNI_WHEEL_R  0.0190f // 19.0mm wheel radius
  #define RAD_S_TO_RPM 458.3664f  // rad/s to RPM with 1:48 gearbox scaling for commanding motor 
  #define GEAR_RATIO  0.02083f    // 1/48 gearbox ratio
#else
  #define OMNI_WHEEL_D  0.240f // 240.0mm distance from robot center to wheel center
  #define OMNI_WHEEL_R  0.0635f // 63.5mm wheel radius
  #define RAD_S_TO_RPM 458.3664f  // rad/s to RPM with 1:48 gearbox scaling for commanding motor 
  #define GEAR_RATIO  0.02083f    // 1/48 gearbox ratio
#endif

// Math constants
#define RPM_TO_RAD_S  0.1047f // 1 rpm == 0.1047 rad/s 
#define OMNI_SINE_120 0.866025f // Sine(120 degree) in rad unit
#define F2_SQRT3      1.1547f // 2/sqrt(3)

// Control system related
#define LOOP_TIME         8 // Loop time is 8ms -> 125Hz

// Odom mouse sensor ADNS5050
#define ADNS5050_SPI_NCS  5
#define ADNS5050_SPI_SIO  19
#define ADNS5050_SPI_SCK  18
#define ADNS5050_NRST     23

// Global Typedef

// Bluepad32
ControllerPtr myControllers;

// Robot odometry and cmd_vel
odometry_t omni_odom;// Robot odometry frame data
odometry_t optical_odom;// Optical odometry (only X and Y vel)
odometry_t wheel_odom;// Wheel odometry (Only X and Y vel)

pidConst_t pid_walk_t = {
  3.5f, 0.0005f, 0.005f,   // Walk kPID Kp 1.8 Ki 0.0005 Kd 0.0
  0.005f, 0.26f,        // Walk min and max velocity (m/s)
  0.0f, 0.0f
};// PID constant for linear motion

pidConst_t pid_rotate_t = {
  1.4f, 0.0015f, 0.0f,  // Rotate kPID
  0.0f, 0.0f,
  0.0005f, 3.5f    // Rotate min and max velocity (4.0 rad/s)
};// PID constant for angular motion

pidConst_t pid_twizzles_t = {
  0.0f, 0.3f, 0.0045f,  // Twizzle rotate kPID Kp 0.86 Ki 0.00085 Kd 0.003
  0.0f, 0.0f,
  0.0f, 0.0f 
};// PID constant for twizzles rotate control

cmdvel_t omni_cmdvel;// Robot base-link frame velocity command
headvel_t joy_headvel;
wheelvel_t omni_wheelvel;// Per-wheel velocity command

// FreeRTOS core 0 task
TaskHandle_t Core0_t;

// Global variable
unsigned long runner_millis = 0;
uint8_t main_fsm = 0;

// Communication core
unsigned long bluepad32_millis = 0;
unsigned long debugprint_millis = 0;

uint16_t joycmd = 0;

void sensor_Init() {
#ifndef IROB_UPSIZED
  /* Begin Sensor Initialization */
  adns5050_init(
    ADNS5050_SPI_NCS,
    ADNS5050_SPI_SIO,
    ADNS5050_SPI_SCK,
    ADNS5050_NRST
  );
  // Probe for sensor
  if (adns5050_Probe()) {
    Serial.println("ADNS 5050 probing error!");
    while (1);
  }
  // Set CPI 
  adns5050_setcpi();
  // turn LED on
  adns5050_setLED();
  
  // Start I2C
  Wire.begin();

  // Init magnetometer
  hmc5883l_init();

  // Init Gyro
  itg3205_init();

  // Init HLS_LFCD2 LiDAR
  hls_initLiDAR();
#else
  /* end Sensor Initialization */
#endif
}

void omni_init(){
  encoder_Init();// Initialize ESP32 Encoder interrupt.
  sensor_Init();// Initialize all sensors.
  pinMode(2, OUTPUT);
  pinMode(0, INPUT);

#ifndef IROB_UPSIZED  
  while(digitalRead(0));
  Serial.println("Gyro calibrating");
  digitalWrite(2, HIGH);
  itg3205_calib();
  hmc5883l_getInitialPosZ();
  digitalWrite(2, LOW);
  Serial.println("Done!");
#endif

#ifndef IROB_UPSIZED
  // Initialize fuser
  fuser_Init(
    &omni_odom, // Robot's odometry
    0.0f,        // Filter weight of the wheel odom (vel_x) 0.625
    0.0f,        // Filter weight of the wheel odom (vel_y) 0.625
    1.0f      // Filter weight of the gyro angular velocity (vel_az)
  );
#else
  fuser_Init(
    &omni_odom, // Robot's odometry
    1.0f,        // Filter weight of the wheel odom (vel_x) 0.625
    1.0f,        // Filter weight of the wheel odom (vel_y) 0.625
    1.0f      // Filter weight of the gyro angular velocity (vel_az)
  );
#endif

  /* Begin maneuv3r algorithm */
  maneuv3r_init(
    &omni_odom, // Robot's system-wide odometry
    &omni_cmdvel, // Robot's system-wide cmd_vel
    &pid_walk_t,
    &pid_rotate_t,
    &pid_twizzles_t
    );

  maneuv3r_update_Cmdvel(0.0f, 0.0f, 0.0f);
  /* End maneuv3r algorithm */
}

void task_Init(){
  
  xTaskCreatePinnedToCore(
      loop0, /* Function to implement the task */
      "network", /* Name of the task */
      40000,  /* Stack size in words */
      NULL,  /* Task input parameter */
      0,  /* Priority of the task */
      &Core0_t,  /* Task handle. */
      0); /* Core where the task should run */  
        
}

void setup() {
  motor_omniInit(&omni_wheelvel);// Pass the pointer to Wheel velocity command
  Serial.begin(115200);
  // Initialize Bluepad32
  task_Init();
  omni_init();
}

inline void computeOdom() {
  encoder_doVel();// Estimate Wheel RPM.

#ifndef IROB_UPSIZED
  // Re-using the optical and wheel odometry struct.
  itg3205_getPosZ(&optical_odom);       // Integrate the angular velocity to estimate orientation.
  hmc5883l_getPosZ(&wheel_odom);        // Update robot orientation (az) referenced to north, also update angular velocity.
  fuser_processYaw(&optical_odom, &wheel_odom);// Fuse Gyro angular vel with Mag angular vel.
  
  adns5050_updateVel(&optical_odom);// Get X and Y velocity from mouse sensor.
  odometry_wheelOdom(&wheel_odom);  // Get X and Y velocity from wheel encoders.
  fuser_processOdom(&optical_odom, &wheel_odom); // Fuse Optical flow odom with Wheel odom.
#else
  fuser_processYaw(&omni_odom, &omni_odom);// Fuse Gyro angular vel with Mag angular vel.
  odometry_wheelOdom(&omni_odom);
  
#endif
  odometry_posUpdate(&omni_odom);// Update robot X, Y position by integrating vx and vy.
}


// robot configuration :
//                    +x
//        v1           ^
//       /  \          |
//      /    \  +y <---o
//    v3 ---- v2
// Inverse kinematic below :
inline void cmd_vel(cmdvel_t *command_vel) {
  omni_wheelvel.v1 =
    (command_vel->vly_out +
     (command_vel->vaz_out * OMNI_WHEEL_D)
    ) / OMNI_WHEEL_R;

  omni_wheelvel.v2 =
    ((command_vel->vlx_out * OMNI_SINE_120) +
     (command_vel->vly_out * -0.5) +
     (command_vel->vaz_out * OMNI_WHEEL_D)
    ) / OMNI_WHEEL_R;

  omni_wheelvel.v3 =
    ((command_vel->vlx_out * -OMNI_SINE_120) +
     (command_vel->vly_out * -0.5) +
     (command_vel->vaz_out * OMNI_WHEEL_D)
    ) / OMNI_WHEEL_R;

  omni_wheelvel.v1 *= RAD_S_TO_RPM;
  omni_wheelvel.v2 *= RAD_S_TO_RPM;
  omni_wheelvel.v3 *= RAD_S_TO_RPM;

  motor_pidUpdate();// Do motor PID algorithm
}

void loop() {
     
    //Control loop here
    if ((micros() - runner_millis) > LOOP_TIME * 1000) {
      runner_millis = micros();
      computeOdom();
//      if(abs(joy_headvel.vel) < 0.01)
//        joy_headvel.heading = 0.0;
      maneuv3r_joyTracker(joy_headvel.vel, joy_headvel.heading, joy_headvel.vaz, joycmd);
      cmd_vel(&omni_cmdvel);
    }
}
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

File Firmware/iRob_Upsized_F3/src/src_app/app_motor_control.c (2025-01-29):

#include "app_motor_control.h"

#define ENC_CONST 	937.5f // (1 rev / (16ppr * 4) counts) * (1000Hz) * (60s / 1min)

#define DEADBAND_SPEED	10.0f

// Private variables
int32_t m1_from_float = 0;
int32_t m2_from_float = 0;
int32_t m3_from_float = 0;
int32_t m4_from_float = 0;


// Private typedefs
motor_rpm_t 		*motor_velcmd_t;
motor_rpm_t			*motor_velread_t;

motor_duty_t		motor_pwm_t;

encoder_cnt_t		enc_cnt_t;
encoder_cnt_t		prev_enc_cnt_t;

pid_t	motor1_pid_t = {
	.Kp = 1.0f,
	.Ki = 0.1f,

	.error = 0.0f,
	.Intg_accmu_dt = 0.0f,
	.out = 0.0f
};

pid_t motor2_pid_t = {
	.Kp = 1.0f,
	.Ki = 0.1f,

	.error = 0.0f,
	.Intg_accmu_dt = 0.0f,
	.out = 0.0f
};

pid_t motor3_pid_t = {
	.Kp = 1.0f,
	.Ki = 0.1f,

	.error = 0.0f,
	.Intg_accmu_dt = 0.0f,
	.out = 0.0f
};

pid_t motor4_pid_t = {
	.Kp = 1.0f,
	.Ki = 0.1f,

	.error = 0.0f,
	.Intg_accmu_dt = 0.0f,
	.out = 0.0f
};

void app_motor_control_init(
	motor_rpm_t *motor_command_ptr_t, 
	motor_rpm_t	*motor_feedback_ptr_t
	){
	
	motor_velcmd_t 	= motor_command_ptr_t;
	motor_velread_t	=	motor_feedback_ptr_t;
		
	tim_qdec_init();
	tim_pwm_init();
}

void app_motor_control_doEncoder(){
	tim_qdec_getCount(&enc_cnt_t);// Read count from the CNT registers

	// Calculate the dt of each encoder
	// Enc = (currect_count - previous_count) * constant
	// Enc then accumulate over the time and divide by 4
	// (simple 4 taps FIR moving average filter)
	motor_velread_t->m1_rpm += 
		(float)(enc_cnt_t.enc1 - prev_enc_cnt_t.enc1) * ENC_CONST;
	motor_velread_t->m1_rpm = motor_velread_t->m1_rpm * 0.25f;
	
	motor_velread_t->m2_rpm += 
		(float)(enc_cnt_t.enc2 - prev_enc_cnt_t.enc2) * ENC_CONST;
	motor_velread_t->m2_rpm = motor_velread_t->m2_rpm * 0.25f; 
	
	motor_velread_t->m3_rpm += 
		(float)(enc_cnt_t.enc3 - prev_enc_cnt_t.enc3) * ENC_CONST;
	motor_velread_t->m3_rpm = motor_velread_t->m3_rpm * 0.25f;
	
	motor_velread_t->m4_rpm += 
		(float)(enc_cnt_t.enc4 - prev_enc_cnt_t.enc4) * ENC_CONST;
	motor_velread_t->m4_rpm = motor_velread_t->m4_rpm * 0.25f;
	
	// Z^-1 the encoder data
	prev_enc_cnt_t.enc1 = enc_cnt_t.enc1;
	prev_enc_cnt_t.enc2 = enc_cnt_t.enc2;
	prev_enc_cnt_t.enc3 = enc_cnt_t.enc3;
	prev_enc_cnt_t.enc4 = enc_cnt_t.enc4;
}

void app_motor_control_doPID(){
	// Motor 1
	motor1_pid_t.error = 
		motor_velcmd_t->m1_rpm -
		motor_velread_t->m1_rpm ;
	
	motor1_pid_t.Intg_accmu_dt +=
		motor1_pid_t.error *	
		motor1_pid_t.Ki;
	
	motor1_pid_t.out = 
		(motor1_pid_t.Kp * motor1_pid_t.error) +
		motor1_pid_t.Intg_accmu_dt;
	
	// Capping output 
	if(motor1_pid_t.out > 4095.0f)
		motor1_pid_t.out = 4095.0f;
	if(motor1_pid_t.out < -4095.0f)
		motor1_pid_t.out = -4095.0f;
	
	// Velocity deadband
	if(
		(motor1_pid_t.out > -DEADBAND_SPEED) &&
		(motor1_pid_t.out < DEADBAND_SPEED)
	){
		motor1_pid_t.out = 0.0f;
		motor1_pid_t.Intg_accmu_dt = 0.0f;// reset integrator
	}
	
	
	// Motor 2
	motor2_pid_t.error = 
		motor_velcmd_t->m2_rpm -
		motor_velread_t->m2_rpm ;
	
	motor2_pid_t.Intg_accmu_dt +=
		motor2_pid_t.error *	
		motor2_pid_t.Ki;
	
	motor2_pid_t.out = 
		(motor2_pid_t.Kp * motor2_pid_t.error) +
		motor2_pid_t.Intg_accmu_dt;
	
	// Capping output 
	if(motor2_pid_t.out > 4095.0f)
		motor2_pid_t.out = 4095.0f;
	if(motor2_pid_t.out < -4095.0f)
		motor2_pid_t.out = -4095.0f;
	
	// Velocity deadband
	if(
		(motor2_pid_t.out > -DEADBAND_SPEED) &&
		(motor2_pid_t.out < DEADBAND_SPEED)
	){
		motor2_pid_t.out = 0.0f;
		motor2_pid_t.Intg_accmu_dt = 0.0f;// reset integrator
	}
	
	
	// Motor 3
	motor3_pid_t.error = 
		motor_velcmd_t->m3_rpm -
		motor_velread_t->m3_rpm ;
	
	motor3_pid_t.Intg_accmu_dt +=
		motor3_pid_t.error *	
		motor3_pid_t.Ki;
	
	motor3_pid_t.out = 
		(motor3_pid_t.Kp * motor3_pid_t.error) +
		motor3_pid_t.Intg_accmu_dt;
	
	// Capping output 
	if(motor3_pid_t.out > 4095.0f)
		motor3_pid_t.out = 4095.0f;
	if(motor3_pid_t.out < -4095.0f)
		motor3_pid_t.out = -4095.0f;
	
	// Velocity deadband
	if(
		(motor3_pid_t.out > -DEADBAND_SPEED) &&
		(motor3_pid_t.out < DEADBAND_SPEED)
	){
		motor3_pid_t.out = 0.0f;
		motor3_pid_t.Intg_accmu_dt = 0.0f;// reset integrator
	}
	
	
	// Motor 4
	motor4_pid_t.error = 
		motor_velcmd_t->m4_rpm -
		motor_velread_t->m4_rpm ;
	
	motor4_pid_t.Intg_accmu_dt +=
		motor4_pid_t.error *	
		motor4_pid_t.Ki;
	
	motor4_pid_t.out = 
		(motor4_pid_t.Kp * motor4_pid_t.error) +
		motor4_pid_t.Intg_accmu_dt;
	
	// Capping output 
	if(motor4_pid_t.out > 4095.0f)
		motor4_pid_t.out = 4095.0f;
	if(motor4_pid_t.out < -4095.0f)
		motor4_pid_t.out = -4095.0f;
	
	// Velocity deadband
	if(
		(motor4_pid_t.out > -DEADBAND_SPEED) &&
		(motor4_pid_t.out < DEADBAND_SPEED)
	){
		motor4_pid_t.out = 0.0f;
		motor4_pid_t.Intg_accmu_dt = 0.0f;// reset integrator
	}
	
}

void app_motor_control_commandMotor(){
	
	m1_from_float = (int32_t)motor1_pid_t.out;
	m2_from_float = (int32_t)motor2_pid_t.out;
	m3_from_float = (int32_t)motor3_pid_t.out;
	m4_from_float = (int32_t)motor4_pid_t.out;
	
	if(m1_from_float > 0){
		motor_pwm_t.m1 = (uint16_t)(m1_from_float);
		M1_INB_DN;
	}else if(m1_from_float < 0){
		motor_pwm_t.m1 = (uint16_t)(4095 + m1_from_float);
		M1_INB_UP;
	}else{
		motor_pwm_t.m1 = 0;
		M1_INB_DN;
	}
	
	if(m2_from_float > 0){
		motor_pwm_t.m2 = (uint16_t)(m2_from_float);
		M2_INB_DN;
	}else if(m2_from_float < 0){
		motor_pwm_t.m2 = (uint16_t)(4095 + m2_from_float);
		M2_INB_UP;
	}else{
		motor_pwm_t.m2 = 0;
		M2_INB_DN;
	}
	
	if(m3_from_float > 0){
		motor_pwm_t.m3 = (uint16_t)(m3_from_float);
		M3_INB_DN;
	}else if(m3_from_float < 0){
		motor_pwm_t.m3 = (uint16_t)(4095 + m3_from_float);
		M3_INB_UP;
	}else{
		motor_pwm_t.m3 = 0;
		M3_INB_DN;
	}
	
	if(m4_from_float > 0){
		motor_pwm_t.m4 = (uint16_t)(m4_from_float);
		M4_INB_DN;
	}else if(m4_from_float < 0){
		motor_pwm_t.m4 = (uint16_t)(4095 + m4_from_float);
		M4_INB_UP;
	}else{
		motor_pwm_t.m4 = 0;
		M4_INB_DN;
	}
	
	tim_pwm_updateCompare(&motor_pwm_t);
}

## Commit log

2024-07-19 Updated the Gear ratio
2024-07-19 Corrected the Forward kinematic equation.
    [odometry.ino]
2024-07-19 Gear ration is now 1:48, PID retuned.
2024-07-20 SPI is now working properly. TODO: attach LED under the robot chassis.
2024-07-20 Fixed gyro calibration.
2024-07-20 Maneuv3r updates - Only pass the pointer of odometry and cmvvel just once at initialization. - Internal FSM only need 2 states. - Updated PID constant values - For now the ADNS5050 odometry will be o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
    [Maneuv3r_3omni_mouse_odometry.ino, maneuv3r_pos_cmd.ino]
2024-07-22 Lots of updates : - Added odometry fusion between wheel odom and optical flow odom. Using simple complementary filter. EKF soon if I have more time. - Retuned PID, TODO : make twizzles rotate perfect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
2024-07-22 Corrected the Mouse control 2 register address typo and changed CPI to 1375.
    [adns_5050.ino]
2024-07-22 Correctly type cast int into float before calculating gyro offset value.
    [itg3205.ino]
2024-07-23 Added motor drive electronics design.
    [DRV8835_mini_drive v15.brd, DRV8835_mini_drive_v6.sch]
2024-07-23 Added Robot mechanical design.
    [iRob_V1_base v19.f3z]
2024-07-25 no longer use error_percent.
    [motor.ino]
2024-07-25 Change back distance tolerance back to 1cm. Twizzle rotate max at 2.5rad/s
    [maneuv3r_pos_cmd.ino]
2024-07-25 Added complementary filter between Gyro and Mag sensor. MORE TEST NEEDED.
2024-07-26 Retuned twizzles PID and added core 0 task preparing for networking taks.
2024-07-26 Read surface quality everytime we read the delta X and delta Y count. Useful for bad surface detection and lens cover warning.
2024-07-26 Lower the max angular velocity in twizzles and tighten up the rotation tolerance.
    [maneuv3r_pos_cmd.ino]
2024-07-26 Change motor 1 Kp to 4.0
2024-07-26 Added schematic of DRV8835 mini drive.
2024-07-30 Example code of using Bluepad32 with ESP32.
2024-08-01 absolute angular position CW rotate roll-over corrected.
    [complementary.ino]
2024-09-15 - Fused Gyro with Magneto with conplementary. - now using position control instead of velocity command from joy.
2024-10-04 Added the breakout board design of ADNS5090, the better sensor compare to ADNS505.
    [adns5090_breakout.brd]
2024-10-04 readjusted the conversion factor of the ADNS5050 after lens adjustment.
2024-11-25 Added the F3 DISCO and ESP32 Upsized iROB hardware, also added original CAD design file.
    [adns_5050_breakout_v9.brd, iRob_BasePlate_1.dxf, iRob_BasePlate_LiDAR.dxf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]
2024-11-25 Added support code for iROB Upsized manual control (No Optical flow) TODO : Tidy the code.
2024-11-25 Now using macro to define the optical flow scaling constant.
2024-11-25 Added via stitching in the iRob Upsized ESP32DOIT design.
2024-12-19 Added firmware for iRob-upsized ESP32.
2025-01-02 Now making use of the DLPF of the MPU6050 and corrected the typo in calibratoin routine.
    [mpu_driver.ino]
2025-02-25 Big update - maneuv3r is now default to absolute X,Y position instead of Dir,heading. - Retuned PID and FLO sensor scaling. - renamed stdodom to stdirob.
2026-07-14 Added initial code of iRob ETH with TCP server working. TODO : Finalize the communication part.
    [iRob_ETH.f3z]
2026-07-17 Updated control loop and communication parts - Added the ROS communication packet handler and processor. - Control loop is now running with TIM2 with the ISR placed in SRAM for low latency. - Removed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
    [gpio.c, gpio.h]
2026-07-19 Added the encoder velocity estimator. TODO: tune the IIR filter.
2026-07-19 Keep track of the project settings.
2026-07-28 Updated control to use encoder tracking filter and make the ISR run all the time. TODO : add the Count per second to RPM conversion with gear box scaling.
2026-08-03 Added TIM3 for PWM and renamed .c files for other timer to make them more relevant.
2026-08-03 - Added debug command type - fixed the memory access hardfault caused by Keil compiler over-optimize. - Fixed the TCP socket Id to '3'
2026-08-03 Encoder pins now default to internal pull down. TODO : Check if it's still 5V tolerance.
    [gpio.c]
2026-08-03 Added J-Scope project file for encoder debug.
2026-08-03 Updated iRob ETH schematic annotation.
2026-08-08 Added encoder feedback data transmission. TODO : test real control with motor.
2026-08-08 Fixed the steady state error of the Velocity estimator by adding more precision to deadband.
2026-08-08 Make sure to have some cooldown before allowing the encoder data to be send again after received protocol command.
2026-08-09 Updated the millis() function export.
2026-08-18 Updated TIM3 PWM control. - Frequency is now properly set to 14.6kHz. - PWM control method is now PWM+polarity. - DRVEN pin is now a single pin and already configured and used.
2026-08-18 Keep track of the project setting files.
2026-09-06 Updated LED control that capable of supporting all types of LED polarity.
2026-09-06 Added the schematic for iRob_ETH V1.1 .
2026-09-08 Added the rollover for the encoder observer and corrected the PWM+DIR control.
2026-09-08 Keep track of project files.
2026-09-12 Fixed the integral reset and clamped it to 20% max of output.

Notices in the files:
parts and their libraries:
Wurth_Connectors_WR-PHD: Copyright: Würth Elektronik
